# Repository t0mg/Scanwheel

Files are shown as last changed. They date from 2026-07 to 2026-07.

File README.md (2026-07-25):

# Scanwheel

Scanwheel is a drum style mechanical television you can build yourself.

It features five windows side by side, each taking advantage of the same scanning drum, but with separate
LEDs to allow separate images. The windows are a luxurious 9mm x 8mm each, with 20 scan lines.

The software uses the Pico's PIO hardware to drive the LEDs, allowing extremely high horizontal resolution,
so the image quality is a lot better than the 20p line count would imply.

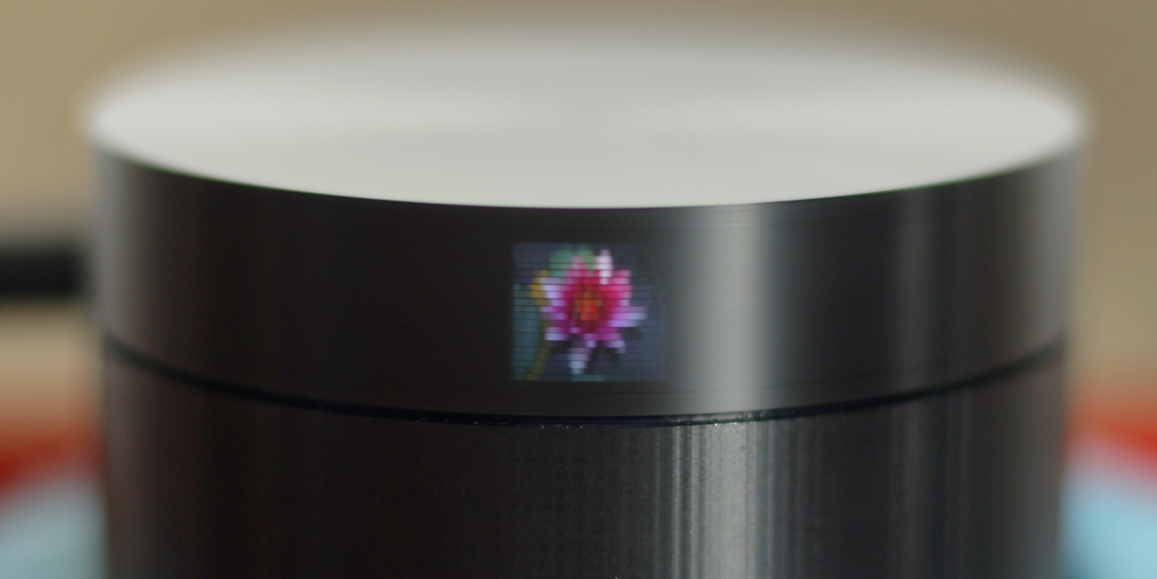
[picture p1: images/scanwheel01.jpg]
A closeup of Scanwheel displaying an image of a flower


There's an accompanying [video](https://example.com/docs) showing the build process, with footage of it in action.

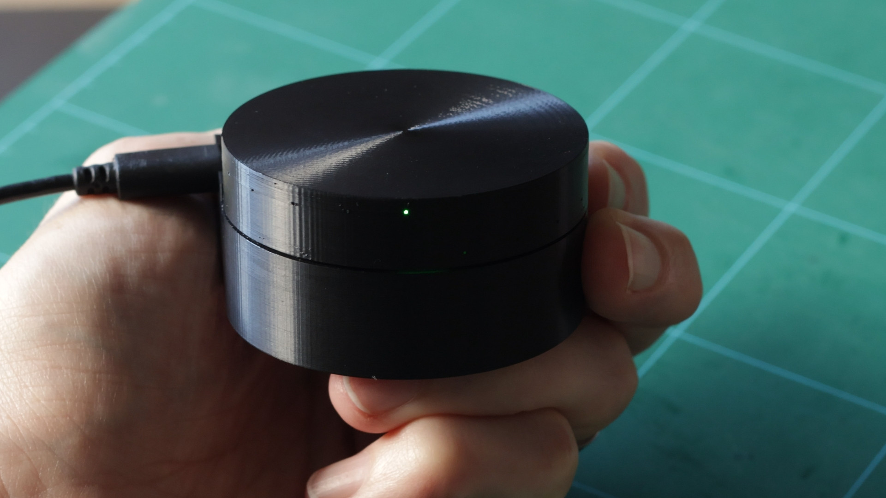
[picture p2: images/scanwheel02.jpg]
Scanwheel build video (https://youtu.be/41b8fw3_wP8)


## Parts

You'll need the following components:

`Symbol Technologies 21-02485 stepper motor`
Old but still widely available online. It has an unusual wiring setup, but it can be used as a bipolar
stepper motor by cutting the white wire before it goes into the 4 pin connector as described
[here](https://web.archive.org/web/20100520003941/http://www.picaxe.orconhosting.net.nz/stepdemo.jpg).

`A4988 based StepStick`
Something like the [Pololu 1182](https://www.pololu.com/product/1182). There's a potentiometer to adjust
the current limit. Turn it down as low as it will go before the motor stops turning - it will be almost
at the bottom end of the pot's range.

`100uF Capacitor` Across motor power & ground.

`Raspberry Pi Pico` Doesn't matter which, but use a Pico W if you want to stream wirelessly to the device.

`LEDs` In the design presented here there's a single RGB LED and 4 white LEDs, which seemed like a good
compromise between wiring complexity and image quality.

`Resistors` Each LED needs a current-limiting resistor. The R, G and B channels need to be matched in 
brightness to each other, and the overall RGB brightness needs to be matched to the white LEDs. All of
them together must draw no more than 50mA from the Pico's GPIO pins.

This means you need to determine the resistor values for the specific LEDs you have sourced - measure
the actual current drawn with your LED and resistor connected.

I found that the red channel of the RGB LED was the deciding factor, at 10.75mA with a 120R resistor.
Matching that brightness required 260R for green (2.9mA), 220R for blue (2.8mA) and 82R for white (4.6mA)

## Printing

The 3D models are in the `parts` directory. There are three printed parts; the base, the drum and a lid.

They will fit best if they are scaled to compensate for shrinkage during printing - on my printer,
using PLA, I find that a scale of 100.33% in X and Y and 100% in Z achieves this.

The base and the lid don't need any special treatment, but the drum requires a bit of care in printing.
Use the highest quality settings - small layer height and low speeds - because small flaws in the pinholes
are very visible in the final display.

The sides of the drum are a
single wall thick. In Orca Slicer this means you need to set 'Wall Generator' to 'Arachne'. The infill
should be 100%.

The [OpenSCAD](https://openscad.org/) model for the drum is included, allowing you modify the design.
One of the parameters is nozzle diameter, and if your printer supports a 0.2mm nozzle I recommend using
that variant. You might find you need to fit a washer over the drum's spindle to increase its moment of
inertia.

## Wiring

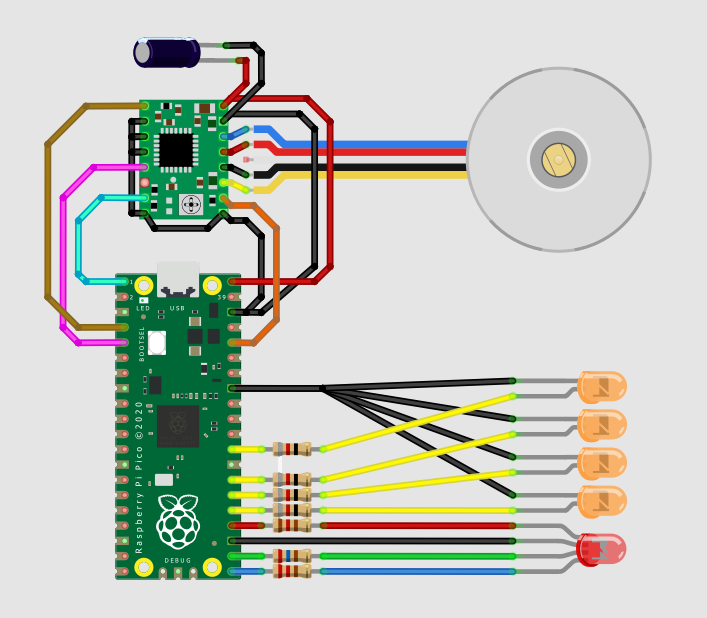
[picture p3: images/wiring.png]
Pictorial wiring diagram

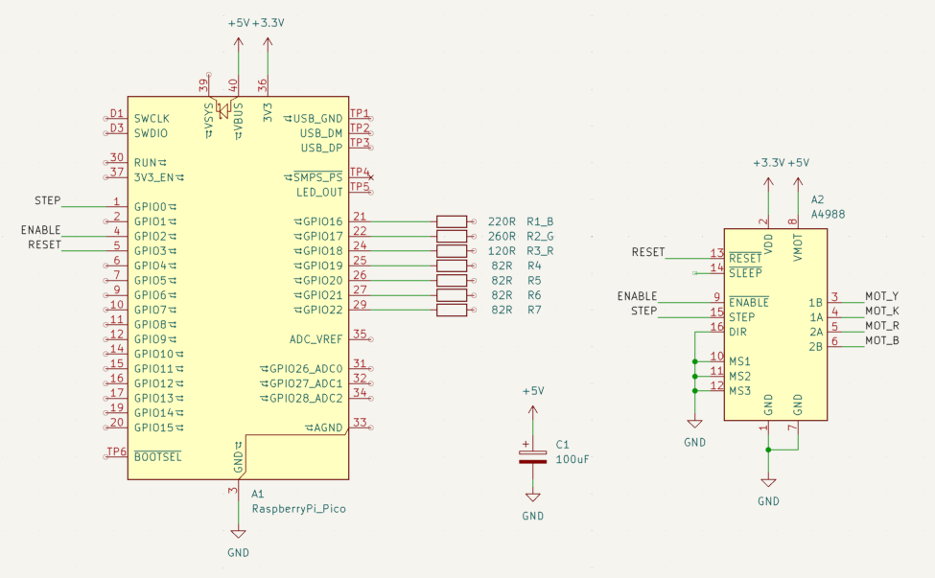
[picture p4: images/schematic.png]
Schematic diagram


## Software

The software runs on Micropython 1.28. The device code is in the `pico` directory - `scanwheel.py` is
the driver, along side some example apps.

The code in `host` runs on the PC - `videostream.py` streams videos over a network connection to
`streaming.py` on the device. `pngdirect.py` converts image files to the raw framebuffer format used
by `scanwheel`.

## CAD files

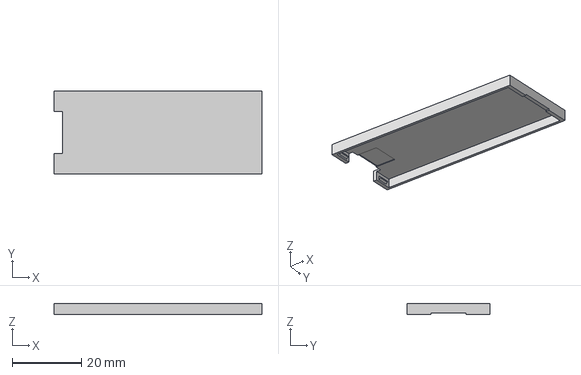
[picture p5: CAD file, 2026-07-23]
parts/Cap.step
60.0 x 23.8 x 3.10 mm

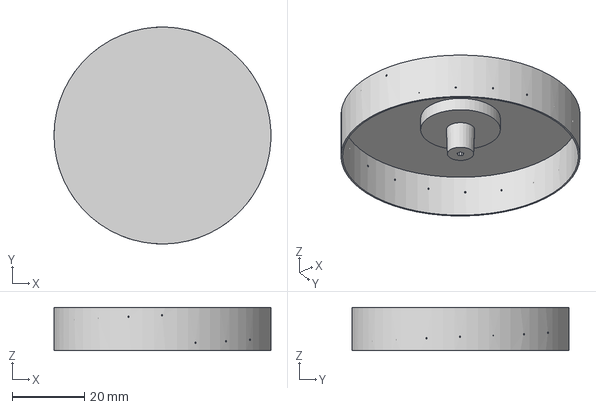
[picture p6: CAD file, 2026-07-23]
parts/Drum.step
60.0 x 60.0 x 12.0 mm

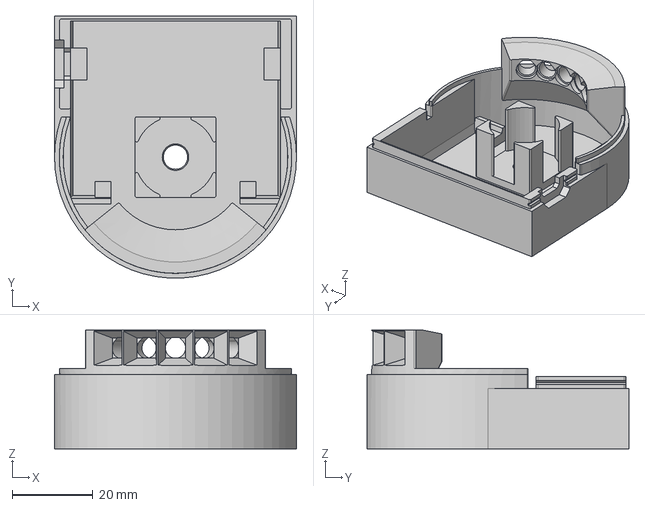
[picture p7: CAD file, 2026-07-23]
parts/Bass.step
60.0 x 65.0 x 29.5 mm

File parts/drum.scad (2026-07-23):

nozzle_diameter = 0.2;

drum_diameter = 60;
drum_height = 12;

scan_lines = 20;
scan_height = 8;
interlaced_fields = 1;
clockwise = false;

slit_height = scan_height / scan_lines;
slit_width = slit_height * 0.75;

mass_height = 4.3;
mass_radius = 10;

spindle_diameter = 6.6;
spindle_bore = 1.5;

drum_radius = drum_diameter / 2;

smoothness = 360;

function line_index(line) =
    let(
        fields = max(1, interlaced_fields),
        field_lines = floor(scan_lines / fields),
        field_line = line % fields,
        carry = scan_lines % fields,
        offset = field_line * field_lines + min(field_line, carry)
    )
    offset + floor(line / fields);


module pinholes() {
    if (interlaced_fields > 1) {
        echo(str(scan_lines, " lines, ", interlaced_fields, " fields:"));
        for (i = [0 : scan_lines - 1]) {
            echo(str(i, ": ", line_index(i)));
        }
    }
    
    union() {
        for (i = [0 : scan_lines - 1]) {
            t = i / scan_lines;
            l = line_index(i);
            z = l / scan_lines;
            translate([0, 0, z * scan_height + (drum_height - scan_height) / 2 + slit_height / 2])
                rotate([0, 0, t * (clockwise ? -360 : 360)])
                    translate([drum_radius / 2, 0, 0])
                        cube([drum_radius, slit_width, slit_height], center=true);
        }
    }
}

module drum() {
    wall_limit = 0.4;

    difference() {
        translate([0,0,0])
            cylinder(h=drum_height, r=drum_radius, $fn=smoothness);

        union() {
            translate([0,0,-1])
                cylinder(h=drum_height, r=drum_radius - wall_limit, $fn=smoothness);
            
            translate([0,0,(drum_height - scan_height) / 2 - 0.5])
                cylinder(h=scan_height + 1, r=drum_radius - nozzle_diameter, $fn=smoothness);
            
            pinholes();
        }
    }
}

module mass() {
    translate([0,0,drum_height - mass_height])
        cylinder(h=mass_height, r=mass_radius, $fn=smoothness * mass_radius / drum_radius);
}

module spindle() {
    spindle_lift = 0.7;

    difference() {
        translate([0,0,spindle_lift])
            linear_extrude(height=drum_height-spindle_lift, scale=1.125)
                circle(r=spindle_diameter / 2, $fn=smoothness * spindle_diameter / drum_radius);
        
        union() {
            translate([0,0,0])
                cylinder(h=drum_height, r=spindle_bore / 2, $fn=30);
            
            for (i = [0 : 5]) {
                rotate([0, 0, i * 360 / 5])
                    translate([spindle_bore / 2, 0, 0])
                        cylinder(h=10, r=0.2, $fn=15);
            }
        }
    }
}

module section() {    
    translate([-drum_radius, 0, -1])
        cube([drum_diameter, drum_diameter, drum_height + 2]);
}


difference() {
    union() {
        drum();
        mass();
        spindle();
    }
    
    //section();
}

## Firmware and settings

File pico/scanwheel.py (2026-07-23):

import array, time, math
import micropython
import machine, rp2, uctypes
import framebuf

def max_factor(value):
    return value & -value

def bit_length(value):
    return math.frexp(value)[1] - 1

def lerp(a, b, t):
    return a + (b - a) * t


def pio_assemble(pclk):
    assert(pclk >= 2)
    
    @rp2.asm_pio(sideset_init=rp2.PIO.OUT_LOW, out_init=(rp2.PIO.OUT_LOW,)*8, autopull=True, pull_thresh=8)
    def pio_program():
        out(pins, 8)                        # load the LED states for the spinup
        
        label("spin_up")
        out(y, 32)                          # load the loop counter
        jmp(not_y, "at_speed")              # if it's zero, proceed to scanning
        
        mov(x, y).side(1)       [pclk-2]    # step pin high
        label("spin_hi")
        nop()                   [pclk-2]
        jmp(x_dec, "spin_hi")
        
        mov(x, y).side(0)       [pclk-1]    # step pin low
        label("spin_lo")
        nop()                   [pclk-2]
        jmp(x_dec, "spin_lo")
        
        jmp("spin_up")
        
        label("at_speed")
        out(y, 32)                          # load the line loop counter
        
        wrap_target()                       # main loop
        
        out(pins, 8).side(1)    [pclk-2]    # pixel output...
        mov(x, y)                           # ... +1 clock to load the loop counter
        label("step_hi")                    # output half a line with the step pin high:
        out(pins, 8).side(1)    [pclk-2]    #   pixel output...
        jmp(x_dec, "step_hi")               #   ... +1 clock to loop
        
        out(pins, 8).side(0)    [pclk-2]    # same again, with the step pin low
        mov(x, y)
        label("step_lo")
        out(pins, 8).side(0)    [pclk-2]
        jmp(x_dec, "step_lo")
        
        wrap()
        
    return pio_program



class ScanWheel:
    
    LUM_LEDS = const(4)
    RGB_LEDS = const(1)
    
    def __init__(
        self,
        leds : int = 16,
        step : int = 0,
        enable : int = 2,
        reset : int = 3,
        scanlines : int = 20,
        linewidth : int = 1024,
        framerate : float = 15
    ):
        self.pin_leds = leds
        self.pin_step = step
        self.pin_enable = enable
        self.pin_reset = reset

        chunk_count, linewidth = ScanWheel._calculate_chunk_count(linewidth, scanlines)
        chunk_size = (linewidth * scanlines) // chunk_count
        
        self.frame_w = int(linewidth)
        self.frame_h = int(scanlines)
        self.frame_rate = framerate
        
        self.frame_size = int(self.frame_w * self.frame_h)

        frame_aligned = self.frame_size + chunk_size - 1
        preamble_max = 4096
        scratch_max = max(preamble_max, (frame_aligned + 3) // 4)
        
        self.scratch_array = array.array('I', [0] * scratch_max)
        print(f'allocated {scratch_max * 4} bytes for buffers')
        
        self._create_framebuffer(chunk_size)
        
        self.sm = self._state_machine()
        self.dma = ScanWheel._dma_chain(self.frame_memory, chunk_count, chunk_size, self.sm)
        
        config = ScanWheel.read_config()
        self.hconst = config['hconst']
        self.halign = config['halign']
        self.valign = config['valign']
        
    def _generate_preamble(self, leds_state, ramp_a, ramp_b):
        try:
            preamble = 0
            
            # set the state of the LEDs during spin up
            self.scratch_array[preamble] = int(leds_state) << 24
            preamble += 1

            valign = -self.valign
            
            halign = round((self.hconst * self.frame_rate + self.halign) * self.frame_w)
            if halign < 0:
                valign += (-halign // self.frame_w) + 1
            halign = halign % self.frame_w

            f = 1
            fw = self.frame_rate * self.frame_w
            while True:
                freq =  ramp_b * pow(f, ramp_a)
                w = fw * freq
                if w < self.frame_w:
                    break
                
                self.scratch_array[preamble] = int(w) // 2 - 2
                preamble += 1
                valign += 1
                f += 1

            # stabilise at the target scanline length, and pad to vertical alignment
            for _ in range((self.frame_h * 2) - (valign % self.frame_h)):
                self.scratch_array[preamble] = int(self.frame_w // 2 - 2)
                preamble += 1
                
            #print(f'preamble {preamble} lines, {preamble // self.frame_h} frames / voff {preamble % self.frame_h}')
            
            # transition to normal operation
            self.scratch_array[preamble] = int(0)
            preamble += 1
            
            # set the actual line length
            self.scratch_array[preamble] = int(self.frame_w // 2 - 2)
            preamble += 1
            
            # pad with dummy pixels to set the horizontal alignment
            for _ in range(halign):
                self.scratch_array[preamble] = int(0)
                preamble += 1
        
        except IndexError:
            return -1
        
        return preamble
        


    def start(self, leds_state=0):
        
        # turn on the driver
        machine.Pin(self.pin_enable, machine.Pin.OUT).value(0)
        machine.Pin(self.pin_reset, machine.Pin.OUT).value(1)
        time.sleep_us(1000)
        
        # hand over the LEDs
        for p in range(8):
            machine.Pin(self.pin_leds + p, mode=machine.Pin.ALT, alt=machine.Pin.ALT_PIO0)

        # build the preamble list
        ramp_a = -0.25
        ramp_b = 0.3
        preamble = self._generate_preamble(leds_state, ramp_a, ramp_b)
    
        if preamble <= 0:
            print('preamble overruns scratch buffer')
            for _ in range(8):
                ramp_b *= 0.9
                preamble = self._generate_preamble(leds_state, ramp_a, ramp_b)
                if preamble > 0:
                    break
            if preamble <=0:
                sys.exit()
            
            
            
        # now send that to the state machine
        self.sm.put(self.scratch_array[:preamble])

        # and hand over to the dma chain
        self.dma[0].active(1)
        
        self.frame_buffer.fill(0)
        
    def stand_by(self):
        machine.Pin(self.pin_enable, machine.Pin.OUT).value(0)
        time.sleep_us(1000)
        machine.Pin(self.pin_reset, machine.Pin.OUT).value(0)
        time.sleep_us(1000)
        machine.Pin(self.pin_reset, machine.Pin.OUT).value(1)
        time.sleep_us(1000)

        for p in range(8):
            machine.Pin(self.pin_leds + p, machine.Pin.OUT).value(0)

        red = machine.Pin(self.pin_leds + 2, machine.Pin.OUT)
        red.value(1)

                
    def align(self):
        machine.Pin(self.pin_enable, machine.Pin.OUT).value(0)
        time.sleep_us(1000)
        machine.Pin(self.pin_reset, machine.Pin.OUT).value(0)
        time.sleep_us(1000)
        machine.Pin(self.pin_reset, machine.Pin.OUT).value(1)
        time.sleep_us(1000)

        for p in range(8):
            machine.Pin(self.pin_leds + p, machine.Pin.OUT).value(0)

        green = machine.Pin(self.pin_leds + 1, machine.Pin.OUT)
        green.value(1)
        time.sleep(4)
        
        for _ in range(7):
            green.value(1 - green.value())
            time.sleep(0.25)


    def stop(self):
        # turn off the stepper driver
        machine.Pin(self.pin_enable, machine.Pin.OUT).value(1)
        
        # stop the dma
        try:
            for dma in self.dma:
                dma.config(read=0, write=0, count=0, ctrl=dma.pack_ctrl(enable=False), trigger=False)
        except:
            pass
        
        # stop the pio
        try:
            self.sm.active(0)
        except:
            pass

        # turn off the LEDs
        for p in range(8):
            machine.Pin(self.pin_leds + p, machine.Pin.OUT).value(0)
    
    def _create_framebuffer(self, chunk_size):
        scratch_addr = uctypes.addressof(self.scratch_array)
        
        self.frame_memory = uctypes.bytearray_at(scratch_addr + ((chunk_size - (scratch_addr % chunk_size)) % chunk_size), self.frame_size)
        self.frame_buffer = framebuf.FrameBuffer(self.frame_memory, self.frame_w, self.frame_h, framebuf.GS8)

    @staticmethod
    def read_config():
        config = {
            'hconst': float(0.055),
            'halign': float(0.0),
            'valign': int(0),
        }
        try:
            with open('scanwheel.cfg') as f:
                for line in f:
                    line = line.split('#',1)[0].strip()
                    if line and '=' in line:
                        k,v = line.split('=',1)
                        k = k.strip()
                        v = v.strip()
                        try:
                            config[k] = type(config[k])(v)
                        except:
                            config[k] = v
        except:
            pass
        
        return config
    
    @staticmethod
    def write_config(config):
        with open('scanwheel.cfg', 'w') as f:
            for k, v in config.items():
                f.write(f'{k}={v}\n')


    @staticmethod
    def _calculate_chunk_count(frame_w, frame_h):
        DMA_CHANNEL_COUNT = const(12)
        
        frame_size = frame_w * frame_h
        chunk_count = frame_size // max_factor(frame_size)
        
        if chunk_count >= DMA_CHANNEL_COUNT:
            new_w = 0
            for c in range(2, DMA_CHANNEL_COUNT + 1):
                for b in range(2):
                    s = 1 << max(0, bit_length((frame_size - 1) // c) + b)
                    w = s * c / frame_h
                    if w % 1 == 0:
                        if abs(w - frame_w) < abs(new_w - frame_w):
                            new_w = w

            frame_w = new_w
            
            frame_size = frame_w * frame_h
            chunk_count = max(2, frame_size // max_factor(frame_size))
            
            print(f'frame dimensions are unachievable - using {frame_w}x{frame_h} instead')
        
        return chunk_count, frame_w

    @staticmethod
    def _framerate_params(target_fps, frame_size):
        sys_clock = machine.freq() * 256
        fps = 1000
        pdiv = 128
        sdiv = 3

        for p in range(2, 9):
            d = round(sys_clock / (target_fps * frame_size * p))

            f = (sys_clock // d) / (p * frame_size)
            
            if abs(f - target_fps) < abs(fps - target_fps):
                fps = f
                pdiv = p
                sdiv = d
                
        return sys_clock // sdiv, pdiv

    def _state_machine(self):
        smfreq, pclk = ScanWheel._framerate_params(self.frame_rate, self.frame_size)
        print(f'sm freq {(smfreq)}, {pclk} clocks/pixel; {(smfreq) / (self.frame_size * pclk)} fps  (target: {self.frame_rate})')

        pio_refresh = pio_assemble(pclk)
        sm = rp2.StateMachine(0, pio_refresh, freq=smfreq, out_base=machine.Pin(self.pin_leds), sideset_base=machine.Pin(self.pin_step))
        sm.active(1)
        
        return sm
    
    @staticmethod
    def _dma_chain(frame_buffer, chunk_count, chunk_size, sm):
        print(f'creating dma chain with {chunk_count} chunks of {chunk_size} bytes')
        dma = [rp2.DMA() for _ in range(chunk_count)]
            
        chunk_bits = bit_length(chunk_size)
        for d in range(chunk_count):
            dma[d].config(
                read = uctypes.addressof(frame_buffer) + d * chunk_size,
                write = sm,
                count = chunk_size,
                ctrl = dma[d].pack_ctrl(size=0, inc_read=True, inc_write=False, treq_sel=0, irq_quiet=True, chain_to=dma[(d + 1) % chunk_count].channel, ring_size=chunk_bits),
                trigger = False
            )
            
        return dma
    

def main():
    import sys

    sw = ScanWheel(linewidth=2048, framerate=20)
    
    try:
        sw.align()
        sw.start(leds_state=0b00000111)
        
        def test_card(path, halign, valign):
            try:
                with open(path, 'rb') as f:
                    offset = (valign * sw.frame_w + halign) % sw.frame_size
                    f.readinto(memoryview(sw.frame_memory)[offset:])
                    if offset > 0:
                        f.readinto(memoryview(sw.frame_memory)[:offset])
            except:
                print(f'{path}')
            
        hpixels = 0
        vlines = 0
        test_cards = ['tcb2048.raw', 'tcj2048.raw', 'tcg2048.raw', 'tcf2048.raw']
        card = 3
        test_card(test_cards[card], hpixels, vlines)

        while True:
            ch = sys.stdin.read(1)
            h, v = hpixels, vlines
            reload = False
            
            if ch == 'a':
                h = hpixels - sw.frame_w // 100
            if ch == 'A':
                h = hpixels - sw.frame_w // 10
            if ch == 'd':
                h = hpixels + sw.frame_w // 100
            if ch == 'D':
                h = hpixels + sw.frame_w // 10
            if ch == 'w':
                v = vlines - 1
            if ch == 's':
                v = vlines + 1
            if ch == 'o':
                config = ScanWheel.read_config()
                config['halign'] = (hpixels / sw.frame_w) + sw.halign
                config['valign'] = sw.valign + vlines
                ScanWheel.write_config(config)
                print('wrote scanwheel.cfg')
            
            t = ord(ch) - ord('1')
            if t >= 0 and t < len(test_cards):
                card = t
                reload = True
                
            if reload or h != hpixels or v != vlines:
                hpixels = h
                vlines = ((v + (sw.frame_h // 2)) % sw.frame_h) - (sw.frame_h // 2)
                print(f'valign={sw.valign + vlines}; halign={(hpixels / sw.frame_w) + sw.halign:.2f}')
                test_card(test_cards[card], hpixels, vlines)
            

        
    finally:
        sw.stop()

if __name__ == "__main__":
    main()

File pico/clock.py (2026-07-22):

import time, random
from scanwheel import ScanWheel
from framing import Framing
import micropython, machine, framebuf

tzoffset = 0

def set_time():
    try:
        import network, ntptime

        config = ScanWheel.read_config()
        
        wlan = network.WLAN(network.STA_IF)
        wlan.active(True)
        wlan.connect(config['ssid'], config['wifipw'])

        connection_timeout = 10
        while connection_timeout > 0:
            if wlan.status() >= 3:
                break
            
            connection_timeout -= 1
            print('connecting...')
            time.sleep(1)

        if wlan.status() == 3:
            print('connected')
            for _ in range(10):
                try:
                    ntptime.settime()
                except:
                    pass
            
            global tzoffset
            tzoffset = round(float(config.get('tzoffset', '0')) * 60 * 60)
            print("time:", time.localtime(time.time() + tzoffset))
        
    finally:
        try:
            wlan.disconnect()
        except:
            pass

        try:
            wlan.active(False)
        except:
            pass

def clock():
    sw = ScanWheel(linewidth=512, framerate=20)
    fm = Framing(sw)
    
    sw.stand_by()
    
    set_time()

    rtc = machine.RTC()
    
    try:
        
        NUM_W = 256
        NUM_H = 20
        GLYPH_BYTES = NUM_W // 8 * NUM_H
        
        
        numbers_memory = bytearray(GLYPH_BYTES * 10)
        with open('numbers.raw', 'rb') as f:
            f.readinto(numbers_memory)
            
        mv = memoryview(numbers_memory)
        numbers = [framebuf.FrameBuffer(mv[(9-i) * GLYPH_BYTES : (10-i) * GLYPH_BYTES], NUM_W, NUM_H, framebuf.MONO_HLSB) for i in range(10)]
        
        def number(n):
            return numbers[n % 10]
        
        #pal_lum = framebuf.FrameBuffer(bytearray([0x40]), 2, 1, framebuf.MONO_HLSB)
        pal_rgb = framebuf.FrameBuffer(bytearray([0x07]), 2, 1, framebuf.GS4_HMSB)

        sw.align()
        sw.start(leds_state=0b00000111)
        
        seconds = -1
        
        while True:
            now = time.localtime(time.time() + tzoffset) # (year, month, day, hours, minutes, seconds, subseconds)

            if now[5] == seconds:
                continue

            seconds = now[5]

            for w in range(5):
                fm.windows[ w].fill(0)

            fm.windows[0].blit(number(now[3] // 10), 256, 0)
            fm.windows[1].blit(number(now[3]  % 10),  64, 0)
            fm.windows[2].blit(number(now[4] // 10), 192, 0, 0, pal_rgb)
            fm.windows[3].blit(number(now[4]  % 10),   0, 0)

            fm.windows[4].blit(number(now[5] // 10),   0, 0)
            fm.windows[4].blit(number(now[5]  % 10), 256, 0)
            
            for w in range(5):
                fm.windows[w].rect(0, 0, sw.frame_w, sw.frame_h, 7)
            
            fm.present()
            
    finally:
        sw.stop()
        
if __name__ == "__main__":
    clock()
        

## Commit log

2026-07-05 framebuf support
2026-07-06 windowed framebuffer
2026-07-23 reorganised & documented
    [Bass.step, Cap.step, Drum.step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]
